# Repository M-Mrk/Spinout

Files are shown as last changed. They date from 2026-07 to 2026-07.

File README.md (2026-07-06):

# Spinout

A custom ESP32-S3-based persistence of vision (POV) display capable of displaying images in mid-air while spinning.

## Features

### Display
- Full-color Persistence of Vision (POV) image display
- Image upload through a built-in web interface
- Image scaling and positioning
- Start and stop motor directly from the web interface
- Automatic zero-point synchronization using a Hall effect sensor
- Adjustable display settings for different rotation speeds

## Hardware

- Seeed Studio XIAO ESP32-S3
- DC motor with motor driver
- Hall effect sensor for zero-point detection
- Addressable LED strips mounted on both rotor arms
- Li-Po battery
- Buck converters for stable voltage rails
- Built-in Wi-Fi web server for configuration

## Why?

The world's ending in a few days... It's going to be hot outside, so you'll probably want a fan, right?

The power grid will be down, the lights won't work, and everything will be **fall**(**out**)ing apart. So naturally, the only sensible solution is a fan with **RGB LEDs**. YAY!

Not only does it keep you cool, but it also looks awesome. And thanks to POV magic, you can display anything you want on it...

Including **SOUP**.

## Usage

Power on the device and connect to its Wi-Fi network.

Open the web interface in your browser where you can:
- select the image preset.
- start or stop the motor.

## Images

### Assembled Device

### WEB INTERFACE

### DEMO VIDEO

# Build Your Own

## PCB and Parts

| Reference | Qty | Value | Description | 
| --- | --: | ----- | --- |
| U1 | 1 | Seeed Studio XIAO ESP32-S3 | Main microcontroller | 
| U2 | 1 | DRV8833 | Drives the DC motor |
| M1 | 1 | DC Motor | Main rotating motor |
| D1 | 2 | WS2812B LED Strip | Addressable LEDs mounted on both rotor arms |
| H1 | 1 | Hall Effect Sensor | Rotor zero-point detection and rpm measurement |
| Battery | 1 | Li-Po Battery | Powers the system |
| U3 | 2 | Buck Converter | Generates the required voltages |

## Soldering

Recommended order:

1. Hall effect sensor
2. Motor driver
3. XIAO ESP32-S3
4. Connectors
5. Power circuitry

Follow the [diagram](wiring-diagram.png)

## Case

3D print the provided STL files.

PLA works well for the enclosure, while PETG is recommended for the rotor components because of the mechanical stress during rotation.

## Custom images
You can generate your own image using the python script in the `converter` folder. Just replace on of the existing presets in `firmware/include/frames.h` with the resulting `image_frames` in `frames.h`. Then build the firmware and flash it.

## Programming

**Flashing** is straightforward with PlatformIO:

1. Open the `firmware` folder.
2. Flash the firmware with pio (`pio run -t upload`).

After flashing, connect to the Wi-Fi network created by the device and open the web interface.

**But** you might not want to download pio and the entire toolchain. Then you can grab all the binaries from the [releases](https://github.com/M-Mrk/Spinout/releases/latest). And flash them with the tool of your liking (esptool.py or ESPWebTool). Just follow this table
| Start Address | Name |
| --- | ---- |
| 0x0000 | bootloader.bin |
| 0x8000 | partitions.bin |
| 0xe000 | firmware.bin |

## Assembly

1. Mount the DC motor into the enclosure.
4. Connect the LED strips to the rotors.
5. Mount the rotor arms.
6. Install the battery and buck converters.
7. Verify that the Hall sensor correctly detects the magnet.
8. Close the enclosure.
9. Upload an image using the web interface and start the display.

Everything is designed to fit together without requiring any specialized tools, and the firmware, electronics, and mechanical components were designed specifically for this project.

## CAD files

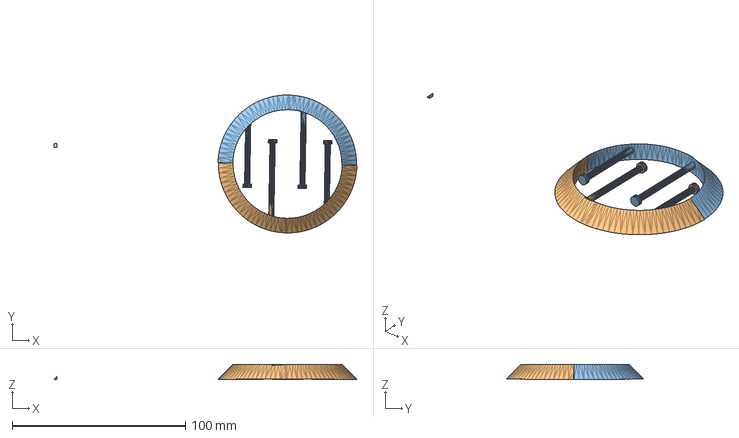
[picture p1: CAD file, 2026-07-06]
Assembly.step
174.8 x 79.6 x 8.56 mm

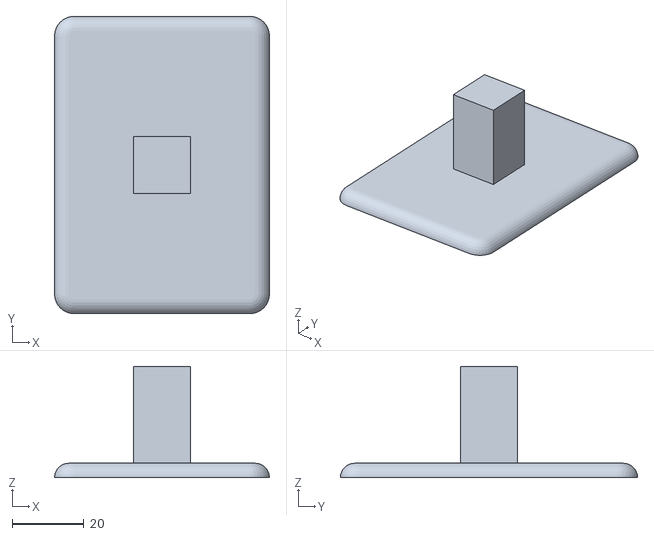
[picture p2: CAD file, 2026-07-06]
CADSP/Lid.stl
60.0 x 83.0 x 31.0

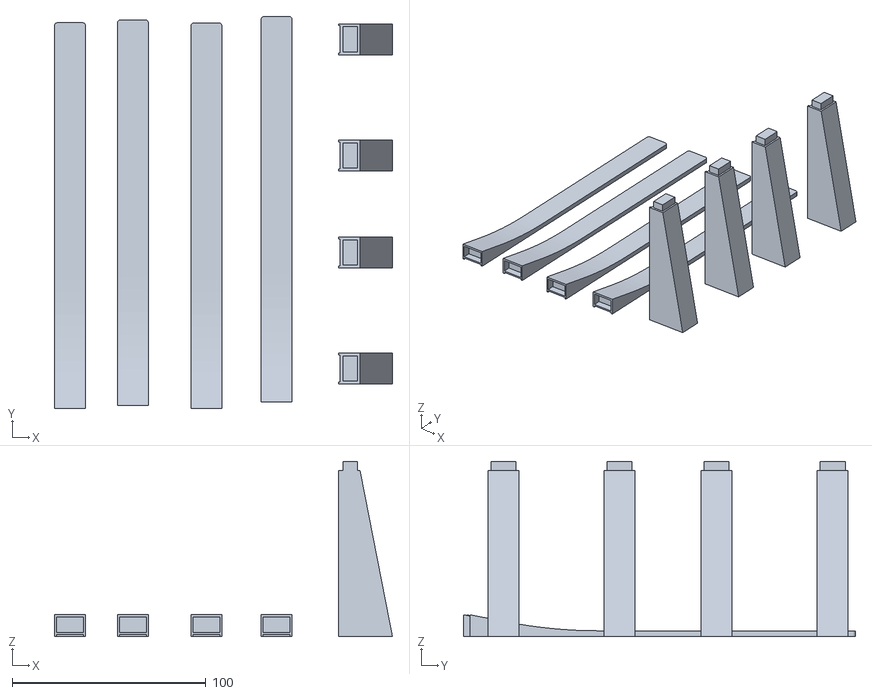
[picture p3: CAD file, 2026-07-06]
CADSP/Rotors.stl
174.5 x 202.4 x 90.4

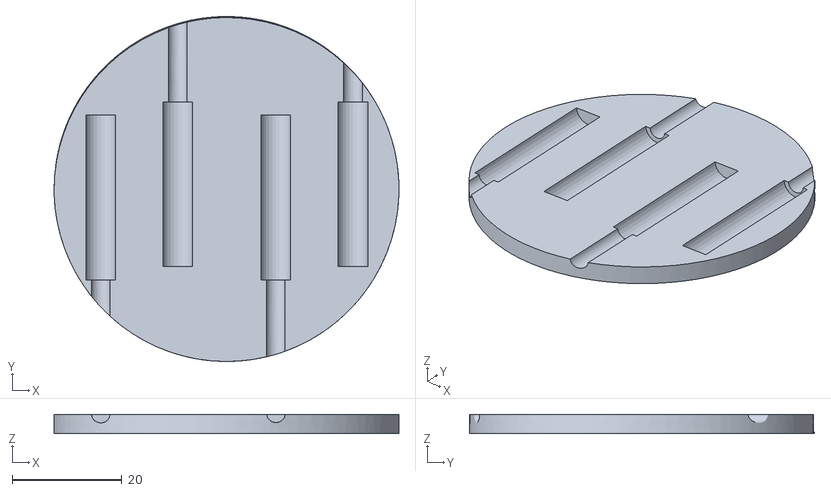
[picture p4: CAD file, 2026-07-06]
CADSP/SliderCase2.stl
62.8 x 62.8 x 3.50

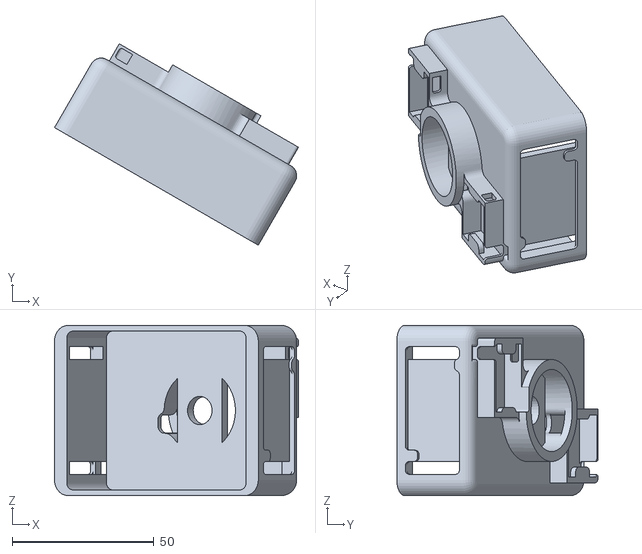
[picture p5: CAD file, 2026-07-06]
CADSP/Case.stl
86.0 x 71.0 x 60.0

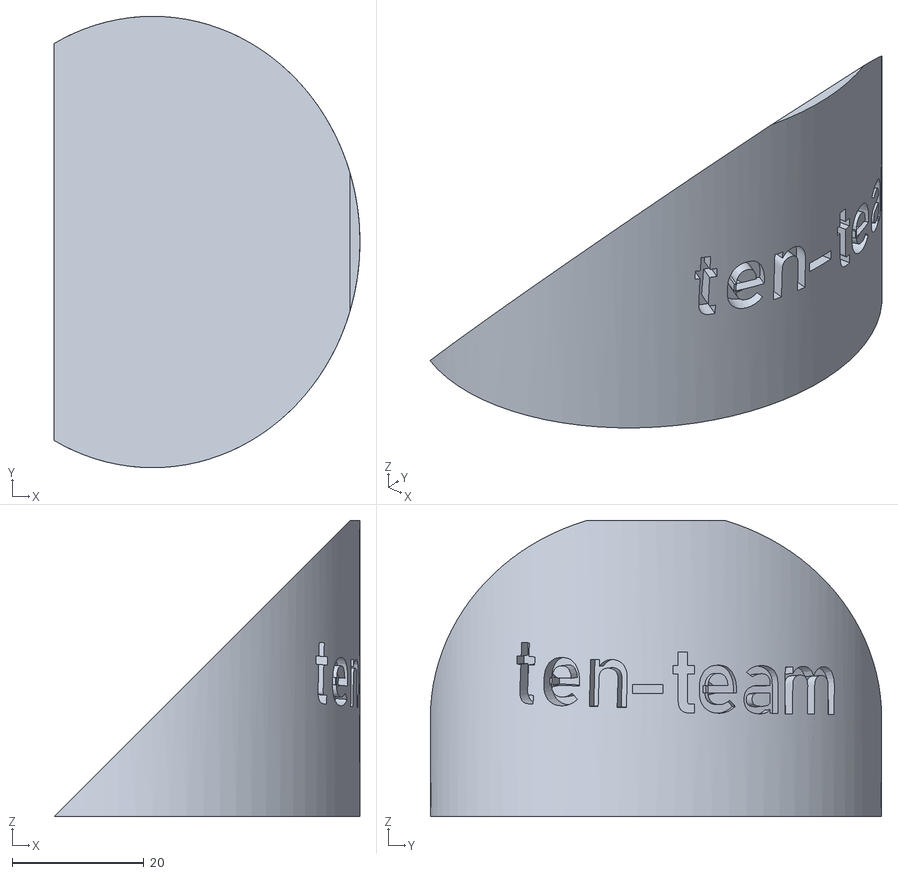
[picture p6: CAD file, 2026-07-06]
CADSP/Tilt.stl
46.5 x 68.6 x 45.0

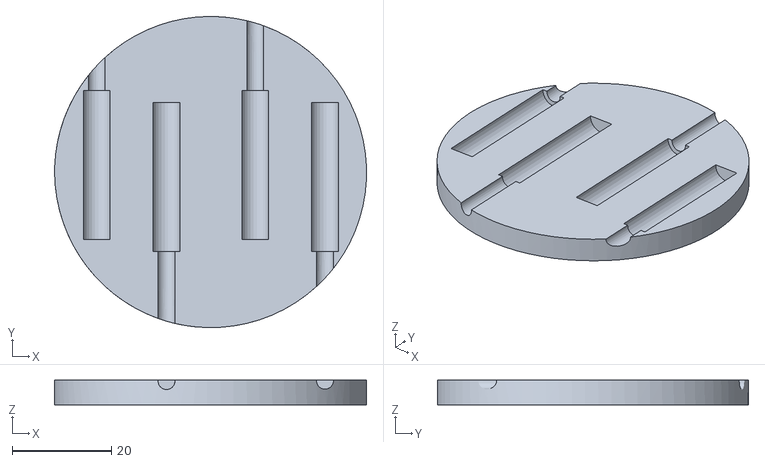
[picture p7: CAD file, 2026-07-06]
CADSP/SliderCase1.stl
62.8 x 62.6 x 5.00

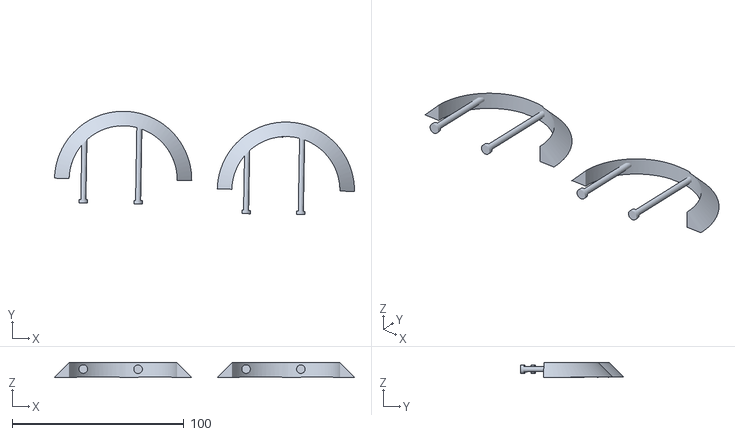
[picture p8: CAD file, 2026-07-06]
CADSP/Sliders.stl
174.8 x 60.3 x 8.56

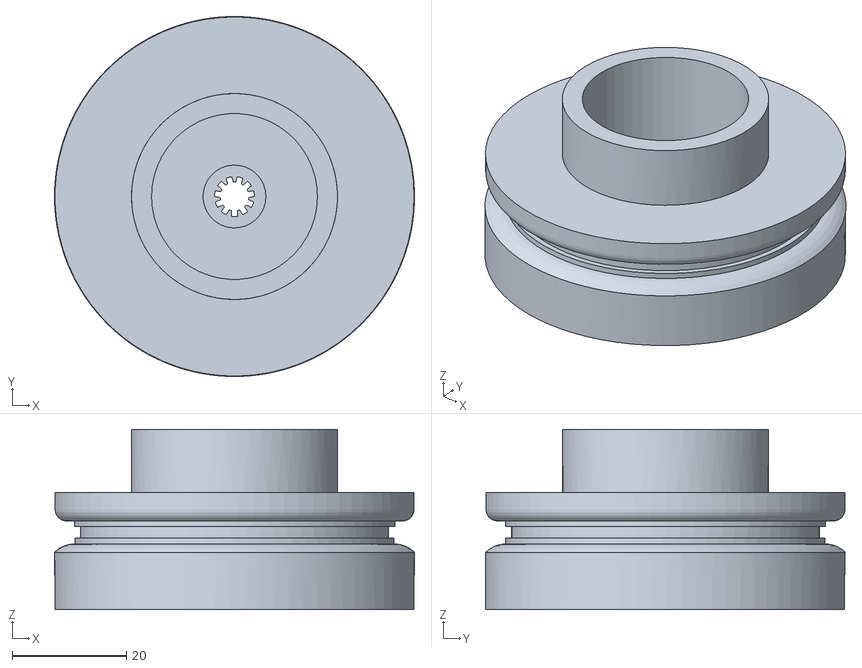
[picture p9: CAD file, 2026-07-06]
CADSP/Base.stl
62.9 x 62.9 x 31.5

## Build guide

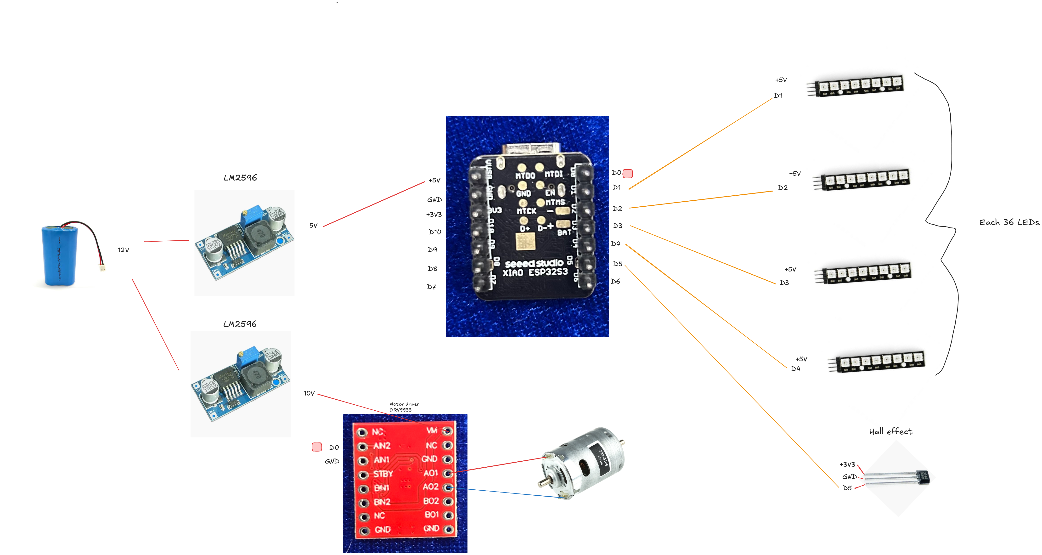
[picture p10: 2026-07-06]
wiring-diagram.png

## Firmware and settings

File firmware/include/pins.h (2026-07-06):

#pragma once
#include <Arduino.h>

#define arm1_pin D1
#define arm2_pin D2
#define arm3_pin D3
#define arm4_pin D4

#define hall_sensor_pin D5
#define receiver_pin D6

#define motor_pin D0

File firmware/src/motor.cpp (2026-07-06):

#include "motor.h"
#include "pins.h"

void Motor::init() {
  analogWriteResolution(motor_pin, this->pwm_resolution);
  pinMode(motor_pin, OUTPUT);
  this->set_motor_speed(0);
}

void Motor::set_motor_speed(uint8_t speed) {
  int constrained_speed = constrain(speed, 0, 100);
  int mapped_speed = map(constrained_speed, 0, 100, 0, this->max_pwm);
  this->current_speed = constrained_speed;
  analogWrite(motor_pin, mapped_speed);
}

void Motor::adjust_motor_speed_once() {
  float rpm = this->hall_sensor.calculate_rps() * 60.0f;
  if (rpm < this->target_rpm * (1.0f - this->target_rpm_tolerance)) {
    if (this->current_speed < 100) {
      this->current_speed += 1;
    }
    this->set_motor_speed(this->current_speed);
  } else if (rpm > this->target_rpm * (1.0f + this->target_rpm_tolerance)) {
    if (this->current_speed > 0) {
      this->current_speed -= 1;
    }
    this->set_motor_speed(this->current_speed);
  }
}

void Motor::adjust_motor_speed(uint32_t end_time_ms, void (*service_web)(), volatile bool* active) {
  #ifdef DEBUG
  Serial.print("Adjusting motor speed. Current speed: ");
  Serial.println(this->current_speed);
  #endif

  int tries = 0;
  while (millis() < end_time_ms) {
    if (active != nullptr && !*active) {
      break;
    }

    if (service_web != nullptr) {
      service_web();
    }

    float rpm = this->hall_sensor.calculate_rps() * 60.0f;
    if (rpm < this->target_rpm * (1.0f - this->target_rpm_tolerance)) {
      if (this->current_speed < 100) {
        this->current_speed += 1;
      }
      this->set_motor_speed(this->current_speed);
    } else if (rpm > this->target_rpm * (1.0f + this->target_rpm_tolerance)) {
      if (this->current_speed > 0) {
        this->current_speed -= 1;
      }
      this->set_motor_speed(this->current_speed);
    } else {
      break; // Exit the loop if RPM is within the tolerance range
    }
    tries++;

    if (service_web != nullptr) {
      service_web();
    }

    if (active != nullptr && !*active) {
      break;
    }

    delay(100); // Small delay to allow the motor speed to adjust
    if (tries > 100) {
      #ifdef DEBUG
      Serial.println("Warning: Unable to stabilize RPM within tolerance after 100 tries.");
      #endif
      break; // Prevent infinite loop in case of issues
    }
  }
}

void HallSensor::update() {
    unsigned long current_time = micros();
    if (last_time != 0) {
        this->last_delta = current_time - this->last_time;
        pulse_count++;
    }
    this->last_time = current_time;
}

#define NUM_MAGNETS 1
float HallSensor::calculate_rps() {
    if (this->last_delta == 0) {
        return 0.0f;
    }
    float period_in_seconds = this->last_delta / 1000000.0f;
    float frequency = 1.0f / period_in_seconds;
    float rps = frequency / NUM_MAGNETS;
    return rps;
}

long HallSensor::micros_till_next_degree() {
    if (this->last_delta == 0) {
        return 0;
    }
    float rps = this->calculate_rps();
    if (rps == 0) {
        return 0;
    }
    float micros_per_degree = 1000000.0f / (rps * 360.0f);
    uint32_t current_micros = micros();
    uint32_t micros_since_last_hall = current_micros - this->last_time;
    long remaining_micros = static_cast<long>(micros_per_degree - micros_since_last_hall);
    if (remaining_micros < 0) {
        remaining_micros = 0;
    }
    return remaining_micros;
}

long HallSensor::micros_till_next_step(uint16_t steps_per_rev) {
    float rps = this->calculate_rps();
    if (rps == 0) return 0;
    float micros_per_step = 1000000.0f / (rps * steps_per_rev);
    uint32_t micros_since_last_hall = micros() - this->last_time;
    long remaining = static_cast<long>(micros_per_step - micros_since_last_hall);
    return remaining > 0 ? remaining : 0;
}

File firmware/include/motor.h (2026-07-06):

#pragma once
#include <Arduino.h>
#include "pins.h"

class Motor;

class HallSensor {
public:
    void update();
    float calculate_rps();
    long micros_till_next_degree();
    long micros_till_next_step(uint16_t steps_per_rev);
    
    unsigned long get_last_delta() const { return last_delta; }
    unsigned long get_pulse_count() const { return pulse_count; }
    
private:
    volatile unsigned long last_time = 0;
    volatile unsigned long last_delta = 0;
    volatile unsigned long pulse_count = 0;
    
    friend class Motor;
};

class Motor {
public:
    HallSensor hall_sensor;
    
    void init();
    void set_motor_speed(uint8_t speed);
    void adjust_motor_speed_once();
    void adjust_motor_speed(uint32_t end_time_ms, void (*service_web)() = nullptr, volatile bool* active = nullptr);

    int get_current_speed() const { return current_speed; }
private:
    int target_rpm = 200;
    float target_rpm_tolerance = 0.05f;
    int pwm_resolution = 8;
    int max_pwm = 255;
    uint8_t current_speed = 0; // Current speed in percentage (0-100)
};

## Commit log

2026-07-06 Added wiring diagram
2026-07-06 Add wiring diagram reference to README
    Added a note to follow the wiring diagram.
